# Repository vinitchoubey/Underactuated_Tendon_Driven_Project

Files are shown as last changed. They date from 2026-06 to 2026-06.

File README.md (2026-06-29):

# Underactuated_Tendon-Driven_Robotic_Gripper

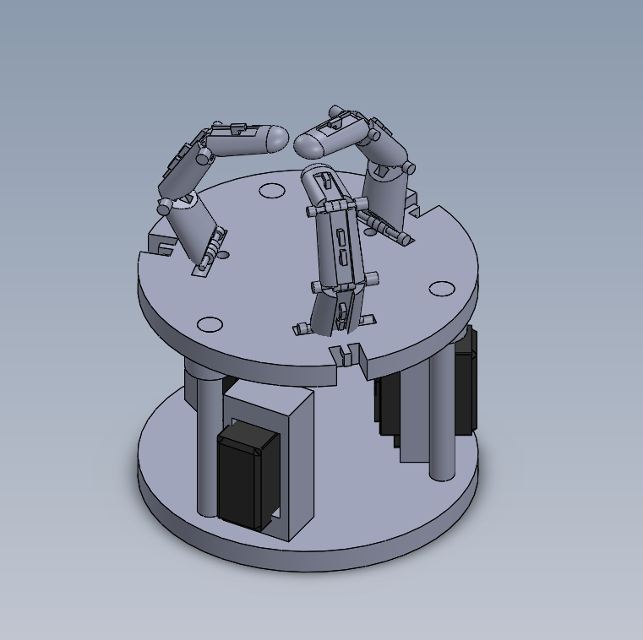
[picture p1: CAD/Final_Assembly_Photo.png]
Gripper


---

## Overview

Design and fabrication of an underactuated, tendon-driven robotic gripper developed
as part of the ME205 Design Lab-1 course at IIT Ropar.

The **Tri-Tendon Gripper** is a 3-finger robotic hand that uses only 3 MG996R servo
motors to control 9 degrees of freedom. Instead of dedicating one motor per joint,
each tendon drives an entire finger — making the system lightweight, energy-efficient,
and capable of adapting to different object shapes automatically.

**Course:** ME205 – Design Lab-1  
**Institution:** IIT Ropar (Indian Institute of Technology, Ropar)  
**CAD Software:** SolidWorks 2021  
**Guide:** Dr. Manish Agrawal

---

## Demo

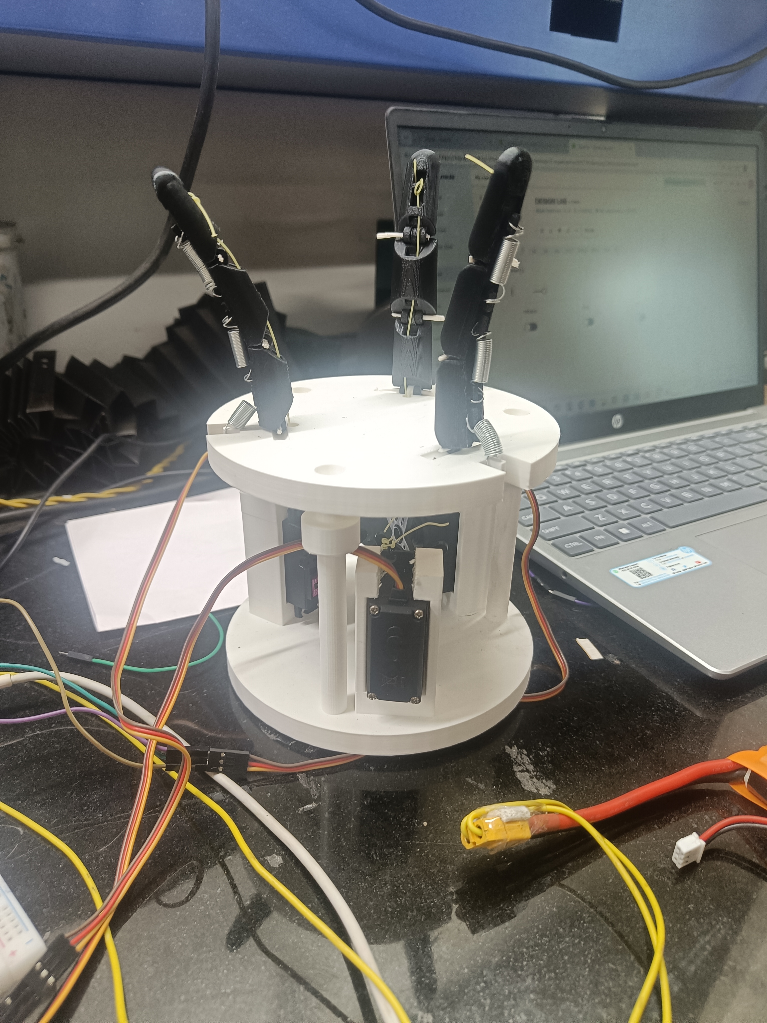
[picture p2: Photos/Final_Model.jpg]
Working Model


[Watch Video Demonstration](Videos/Project_Showcase.mp4)

---

## Working Principle

- **Closing:** Servo motors pull the tendons, curling the fingers inward while
  elongating the return springs mounted at the back of each joint
- **Opening:** When the motor releases, the stretched springs contract and pull
  the fingers back to the open position (passive return)
- **Adaptive Grasping:** Since tendons are not fixed to a single joint, fingers
  automatically wrap around the object's shape without complex programming

---

## Mechanical Design

- 3-finger underactuated structure with 3 joints per finger (9-DOF total)
- Tendons attached to circular servo horns — displacement follows `d = r·sin(θ)`
- Variable spring stiffness across finger length produces a natural curling sequence
- Servos mounted at the base (not on fingers) to minimize moving mass
- Staggered motor start times prevent current spikes and finger collisions

---

## Electronics and IoT

- **Microcontroller:** Arduino Uno R4 WiFi
- **Control Interface:** Blynk IoT platform — mobile app sliders map to servo
  positions via Virtual Pins
- **Power:** DC-DC Buck Converter regulating supply to 6.0V, isolating motor
  current spikes from Arduino logic

---

## Files

| Folder/File | Contents |
|---|---|
| `CAD/` | SolidWorks part and assembly files (.SLDPRT, .SLDASM) |
| `PROJECT_REPORT.pdf` | Full project report |
| `Videos/` | Working model demonstration videos |
| `CAD/Final_Assembly_Photo.png` | CAD render |
| `Photos/` | Physical model photos |

---

## Skills Demonstrated

- CAD modelling and 3D-printed prototype fabrication
- Underactuated mechanism design
- Tendon-spring actuation system
- Arduino programming and IoT integration (Blynk)
- Power electronics and motor control

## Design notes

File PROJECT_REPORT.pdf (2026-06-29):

DESIGN LAB-1
ME-205

### DESIGN AND FABRICATION OF AN UNDERACTUATED TENDON-DRIVEN ROBOTIC GRIPPER

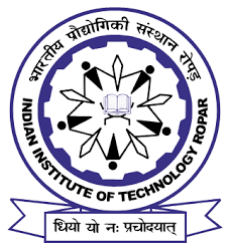
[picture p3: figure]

## DEPARTMENT OF MECHANICALENGINEERING INDIAN INSTITUTE OF TECHNOLOGY ROPAR RUPNAGAR- 140001, INDIA

THU-GROUP(B)

Sr.no | NAME | ENTRY NUMBER
1 | VINIT KUMAR CHOUBEY | 2024MEB1400
2 | UTKARSH SHUKLA | 2024MEB1395
3 | RANVEER GOYAL | 2024MEB1375
4 | SAMEER KUMAR PURBEY | 2024MEB1382
5 | SHIVAM BADYAL | 2024MEB1387

Under the Guidance of: Dr. Manish Agrawal

### TABLE OF CONTENTS

1. Project Overview | Page 3
2. Working Principle | Page 4
3. Mechanical Design and Mechanism | Page 5
- 3.1 Underactuated Finger Motion
- 3.2 Actuation and Transmission (Radial Attachment)
- 3.3 Passive Return Using Springs
- 3.4 Speed and Torque Tuning
4. Under-Actuation and Adaptive Grasping | Page 7
5. Electronics and IoT Integration | Page 8
6. Comparative Analysis | Page 10
7. References and Sources | Page 11

ABSTRACT

This project is about designing and building the Tri-Tendon Gripper, an underactuated, string-driven robotic hand developed at IIT Ropar. Instead of using many motors, we kept the system simple by using just three MG996R servo motor motors to control a total of nine degrees of freedom.

The gripper can automatically adjust its shape while holding objects, so it doesn’t need complicated programming for each joint. It uses a combination of active pulling (through tendons) to close the fingers and a passive spring system to open them again, based on Hooke’s Law.

We controlled the system using an Arduino Uno R4 WiFi along with the Blynk IoT platform, which allowed us to operate the gripper remotely. Overall, this design is lightweight, energy-efficient, and much simpler compared to traditional robotic hands that rely on complex mechanisms and multiple motors.

## 1. Project Overview

Our team designed and prototyped a three-finger robotic gripper based on a string-actuated (tendon-driven) mechanism. The idea was to create a lightweight and efficient system that can perform complex finger movements without relying on many motors.

The final design, which we call the Tri-Tendon Gripper, uses a 9-degree-of-freedom (9-DOF) finger structure but is controlled using only three main tendon lines. Each tendon drives multiple joints in a finger, making the system underactuated.

This approach allows the gripper to automatically adapt to different object shapes while keeping the design simple, compact, and energy-efficient compared to traditional multi-motor systems.

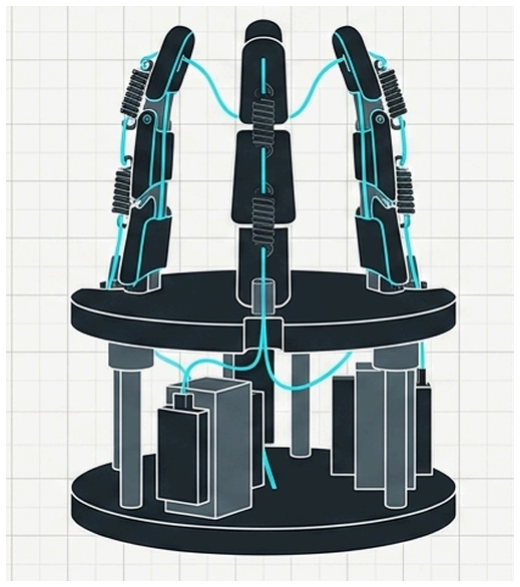
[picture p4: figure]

Fig: String actuated gripper model

## 2. Working Principle

Since our nylon strings can only pull and not push , we had to brainstorm a way to get the fingers to actually open back up once the motor lets go. We went with a "passive" system using springs, which kept the project low-cost and much easier to build.

Instead of using anything complicated, we built normal compression springs directly into the finger joints.

Storing Energy: When our high-torque motors pull the tendons to close the hand, the strings pull against these springs and "squish" them down. This process stores up what is called elastic potential energy inside the spring coils.

The Reset: The moment the motor relaxes the string, all that stored energy is released. The springs push back out to their original shape, which snaps the fingers back into a straight, open position.

The Science: This whole process follows Hooke’s Law. it means that the Force the spring pushes back with is equal to the Stiffness of the spring multiplied by the Distance it was squished. This was a clever trick for our group because it meant we only needed half as many motors, which made our wiring and our Arduino code way easier to manage.

## 3. Mechanical Design and Mechanism

3.1 Underactuated Finger Motion

- Our gripper uses a 3-finger underactuated design, where each finger has multiple joints but is controlled by a single tendon.
- Instead of fixing exact joint angles, the fingers move depending on how they touch the object.
- This helps the fingers naturally wrap around objects, making the grip more adaptive and reliable.

3.2 Actuation and Transmission (Radial Attachment)

- We used MG996R servo motor motors, with tendons attached to holes on a circular servo horn instead of a spool.
- As the servo rotates, the tendon attachment point moves in a circular path, pulling the tendon.
- The tendon movement depends on the servo angle and radius: d=rsin(θ)
- This setup gives higher torque at the start of motion, which helps overcome initial resistance in the system.

3.3 Passive Return Using Springs

- Since tendons can only pull, we added compression springs to bring the fingers back to the open position.
- While closing, the motor expands the springs and stores energy in them.

Ep=0.5*k(Δx)^2

- When the motor releases, the springs come back to original position and help reopen the fingers automatically.

3.4 Speed and Torque Tuning

- Because the springs resist motion during closing, we adjusted the servo speeds differently for each action.
- Grip (85): slower movement to provide more torque and avoid damaging the tendon or stalling the motor.
- Retract (105): faster movement to quickly release the tendon while springs assist in opening.
- This tuning made the system smoother, more stable, and easier to control.

For a continuous servo, 90 is the neutral value → the motor stops.

Values below 90 → rotate in one direction.

Values above 90 → rotate in the opposite direction.

To optimize performance, our team focused on reducing the weight of the moving parts and improving the structural integrity of the hand.

### Design Advantages

- The servos are placed at the base instead of on the fingers, which reduces moving mass and makes the system faster and more efficient.
- Using tendons and springs adds flexibility, so the gripper can handle small impacts without damaging the motor gears.
- This flexible setup acts like a natural shock absorber, making the system safer and more durable.

- It also helps the fingers adjust easily to different object shapes, improving grip without needing complex control

## 4. Under-Actuation and Adaptive Grasping

The defining feature of this project is under-actuation—using only three motors to control nine individual joints.

The Curling Sequence: We achieved a natural "hooking" motion by varying the spring stiffness across the finger. By placing stiffer springs at the base and more flexible springs at the tips, the finger naturally curls from the tip inward, ensuring a more secure wrap around the object.

Adaptive Grasping Capability

- Our tendons are not tied to just one joint, so the fingers can adjust themselves automatically.
- If one part of a finger touches the object early, the tendon keeps pulling the other joints.
- This makes the finger wrap naturally around the object’s shape instead of stopping midway.
- Because of this, the gripper can handle different shapes and sizes easily without extra control.

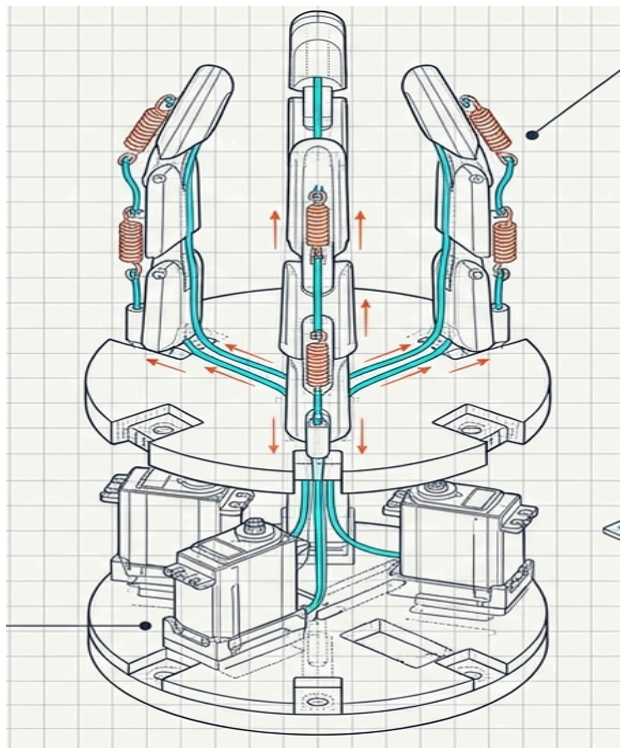
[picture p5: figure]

Fig: anatomy of a gripper system

## 5. Electronics and IoT Integration

The system is powered by the Arduino Uno R4 WiFi, which handles the logic for both local and remote control.

- IoT Interface: We used the Blynk IoT platform for real-time mobile control. We assigned Virtual Pins to represent the finger positions. When a slider is moved on the phone app, the Arduino receives the data and converts it into movement signals for the servos.
- Power Management: A major challenge was the "current spikes" from the motors, which can reset the Arduino. We solved this by adding an external

Buck Converter. This device acts as a steady regulator, keeping the motor power at a constant 6.0 Volts while isolating it from the Arduino's sensitive logic circuits.
- Collision Prevention: To prevent the fingers from crashing into each other, we wrote a "staggered" control script. Instead of moving all fingers at once, the code introduces a tiny delay between each one: Start Time of Finger 2 = Start Time of Finger 1 + Time Delay This also prevents the power system from being overloaded by all three motors starting at the exact same millisecond.

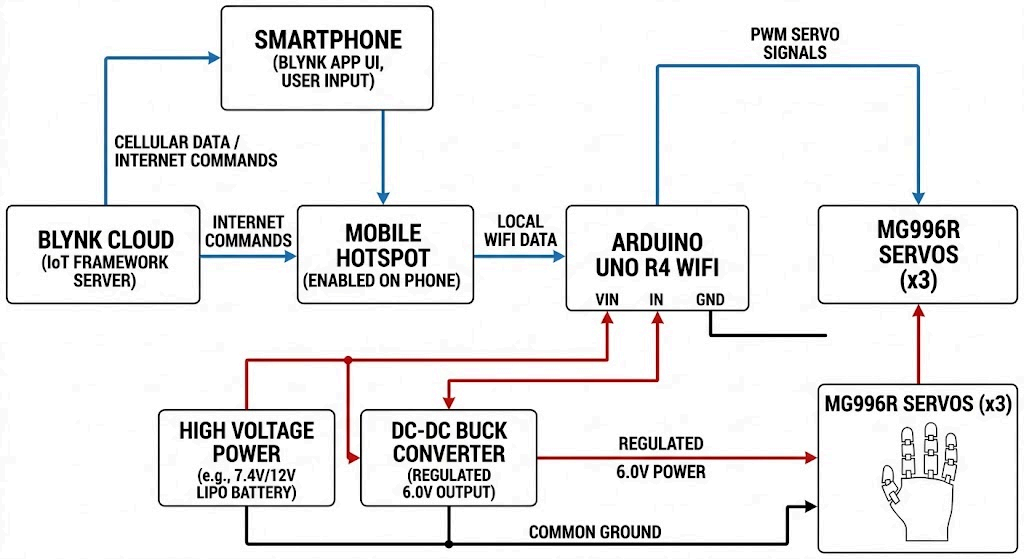
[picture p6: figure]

Fig: system architecture

## 6. Comparative Analysis

The following table summarizes why the Tri-Tendon design was chosen over traditional linkage-based systems.

Feature | Our Tri-Tendon Gripper | Regular Robotic Grippers
Weight | Very light fingers (motors stay in the palm). | Heavy fingers (motors are on the joints).
Shape | Wraps around any shape | Only moves in one fixed way.
Motor Count | Only 3 motors for 9 joints. | Usually needs 9+ motors to do the same thing.

## 7. References and sources

- Birglen, L., & Gosselin, C. M. (2004). "Kinetostatic Analysis of Underactuated Robotic Hands."
- Dollar, A. M., & Howe, R. D. (2010). "The SDM Hand: A Highly Adaptive and Robust Grasping Manipulator."
- Blynk IoT Documentation. "Virtual Pins and Hardware Interfacing for Arduino Uno R4 WiFi." (2024).
- Modular Open-Source Hand Research - Guided our 3D-printing and low-cost design choices.

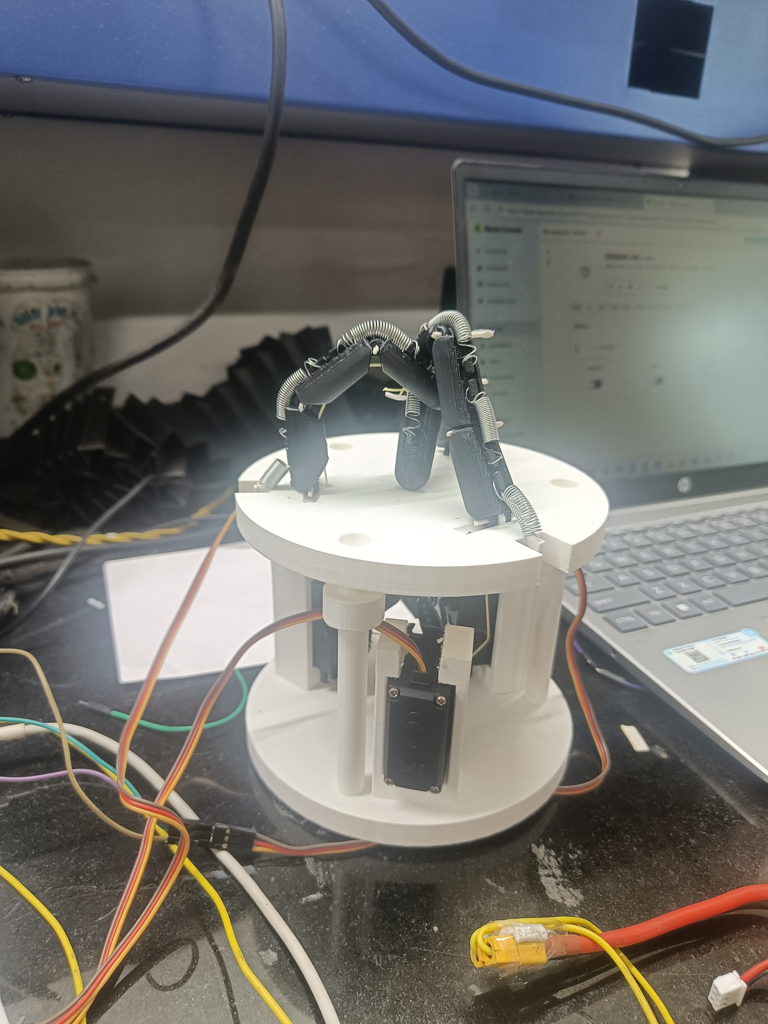
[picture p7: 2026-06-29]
Photos/Closed_Position.jpg

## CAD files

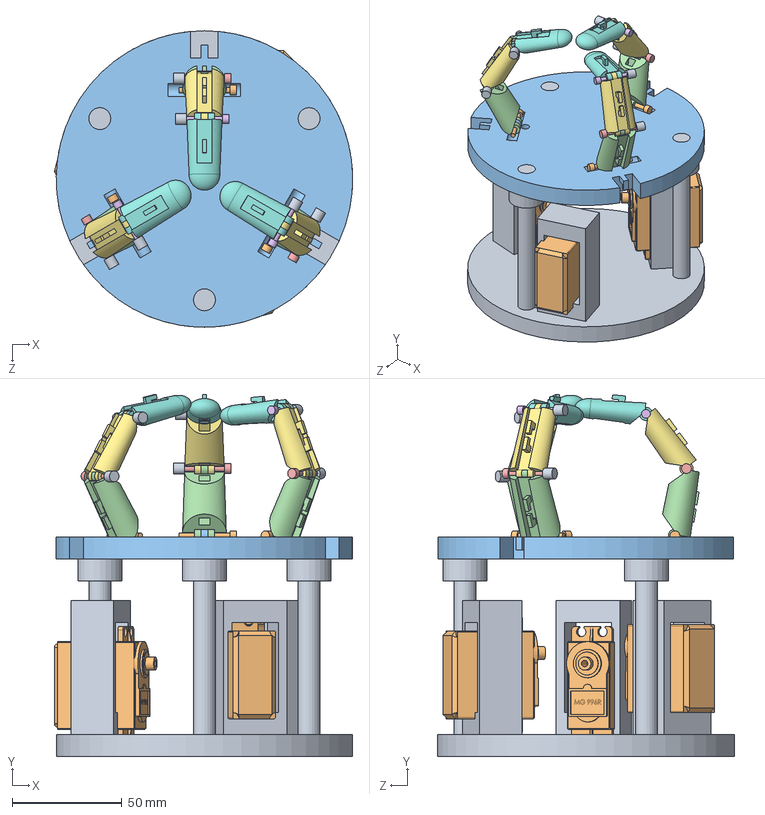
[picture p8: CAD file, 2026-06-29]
CAD/Final Assembly.SLDASM
135.9 x 164.8 x 135.0 mm
Lower Base
##Servo_MG_996R x 3
Upper Base
Base Bone x 3
Finger Joint 1 x 3
Finger Joint 2 x 3
Middle Bone x 3
Tip Bone x 3
Finger Joint 1 cap x 6
Finger Joint 3 x 3

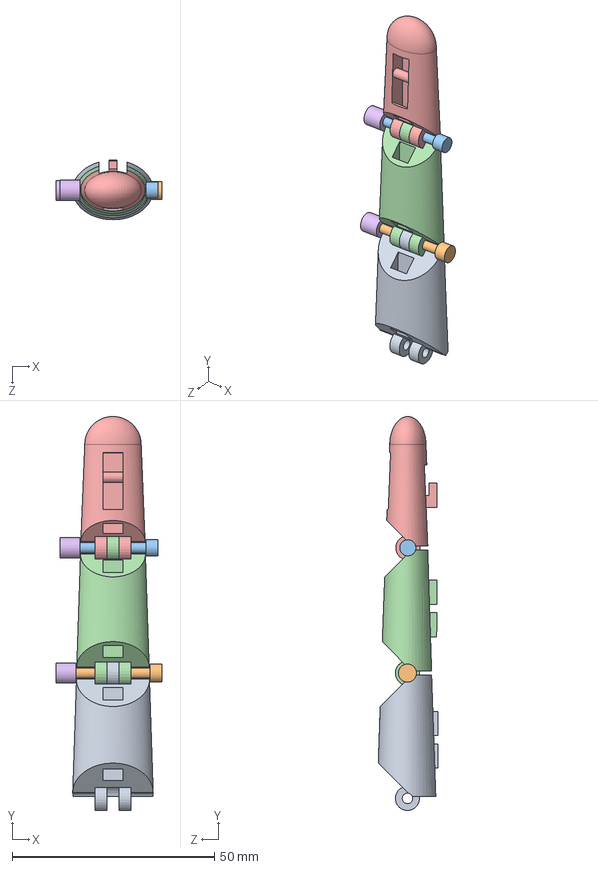
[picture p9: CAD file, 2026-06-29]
CAD/Finger Assembly.SLDASM
26.3 x 97.5 x 14.7 mm
Base Bone
Finger Joint 1
Finger Joint 2
Middle Bone
Tip Bone
Finger Joint 1 cap x 2

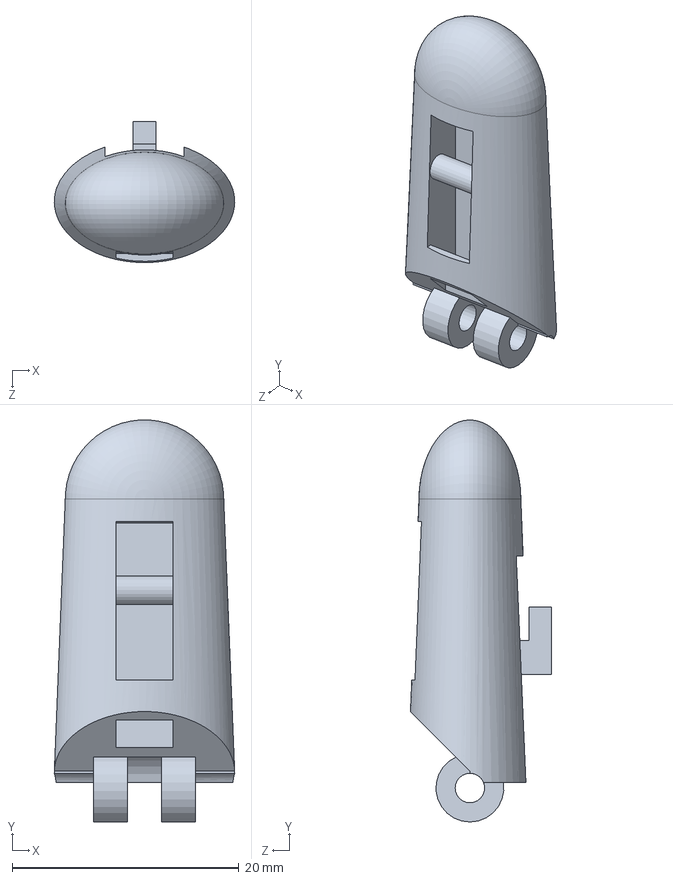
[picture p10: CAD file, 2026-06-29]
CAD/Tip Bone.SLDPRT
15.9 x 35.5 x 12.5 mm

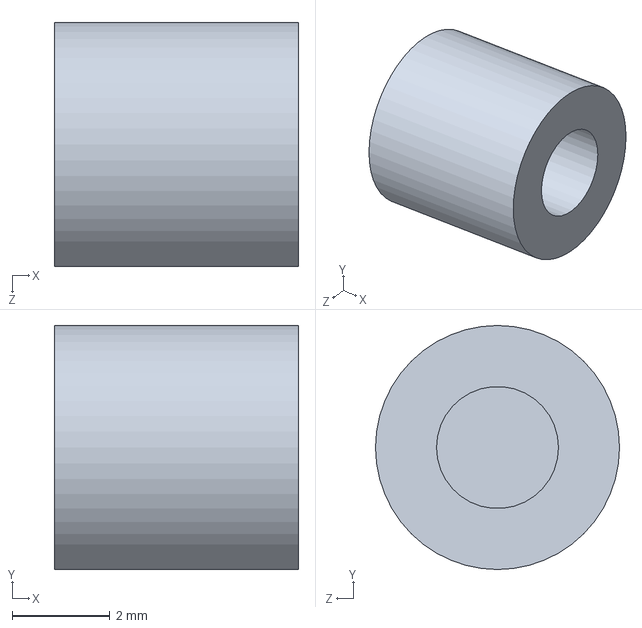
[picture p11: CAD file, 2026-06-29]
CAD/Finger Joint 1 cap.SLDPRT
5.00 x 5.00 x 5.00 mm

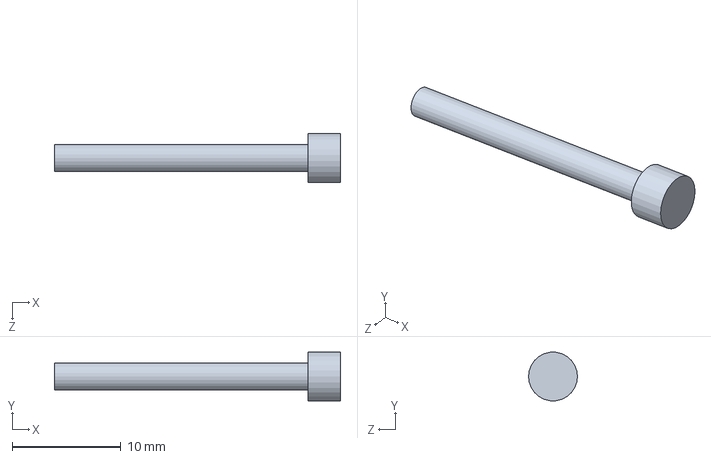
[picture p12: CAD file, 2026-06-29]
CAD/Finger Joint 3.SLDPRT
26.3 x 4.47 x 4.50 mm

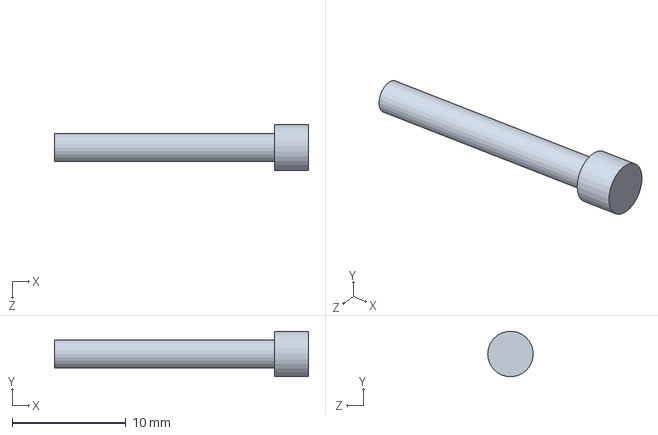
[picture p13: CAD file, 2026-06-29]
CAD/Finger Joint 2.SLDPRT
22.3 x 3.99 x 4.00 mm

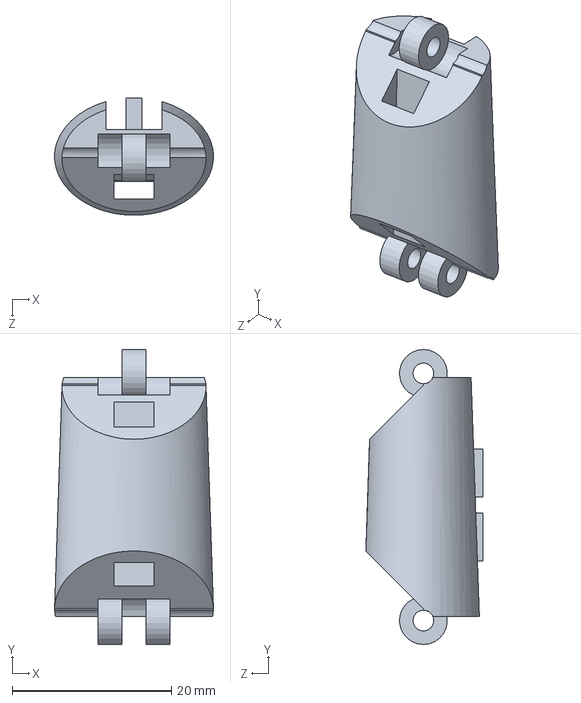
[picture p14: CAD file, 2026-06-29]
CAD/Base Bone.SLDPRT
19.9 x 37.0 x 14.7 mm

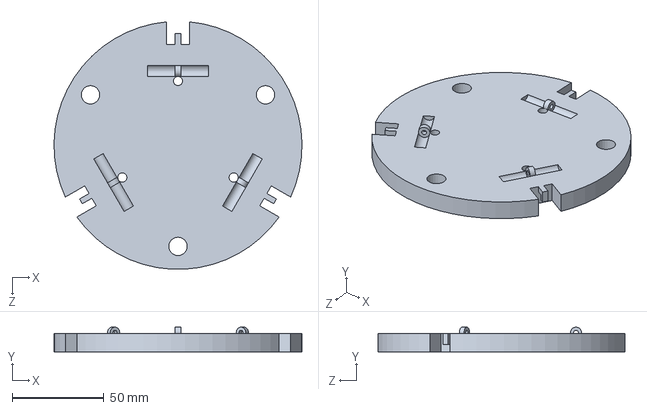
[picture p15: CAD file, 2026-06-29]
CAD/Upper Base.SLDPRT
135.0 x 13.5 x 134.6 mm

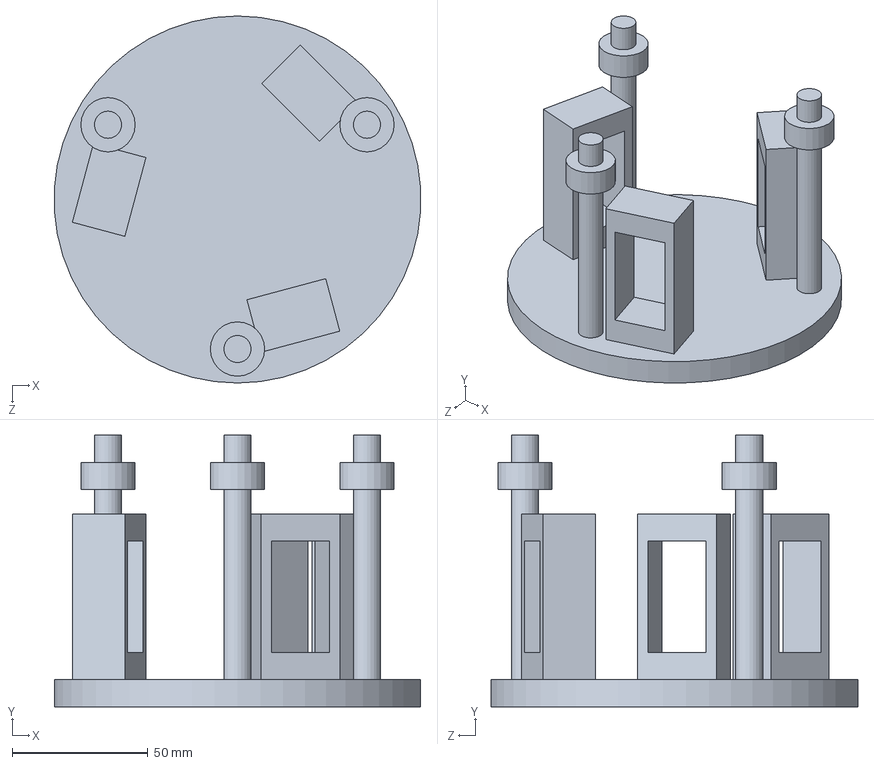
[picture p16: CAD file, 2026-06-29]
CAD/Lower Base.SLDPRT
134.7 x 100.0 x 135.0 mm

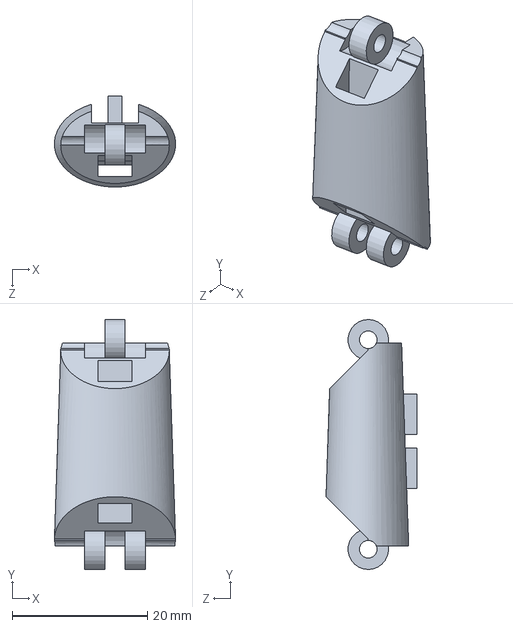
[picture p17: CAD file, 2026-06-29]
CAD/Middle Bone.SLDPRT
17.9 x 37.0 x 13.5 mm

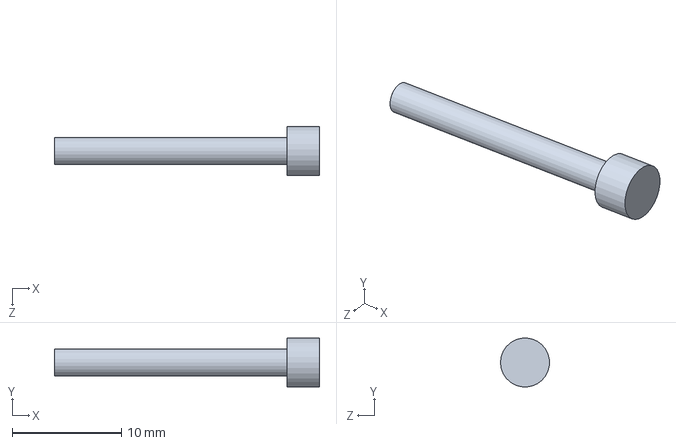
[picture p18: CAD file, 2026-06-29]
CAD/Finger Joint 1.SLDPRT
24.3 x 4.49 x 4.50 mm

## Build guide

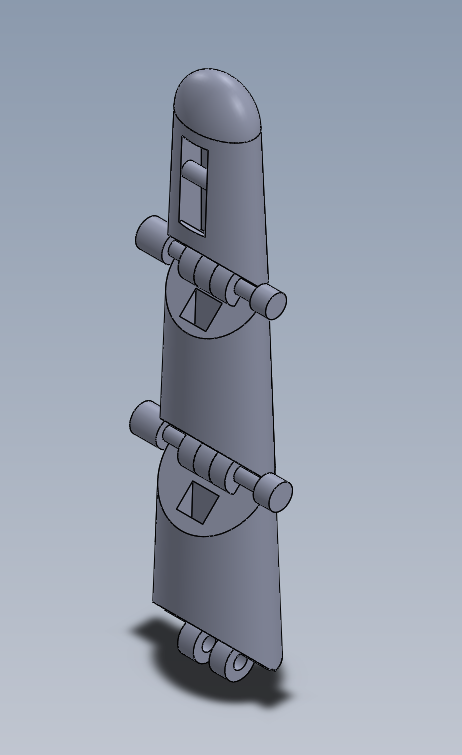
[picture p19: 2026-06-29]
CAD/Finger Assembly 1.png

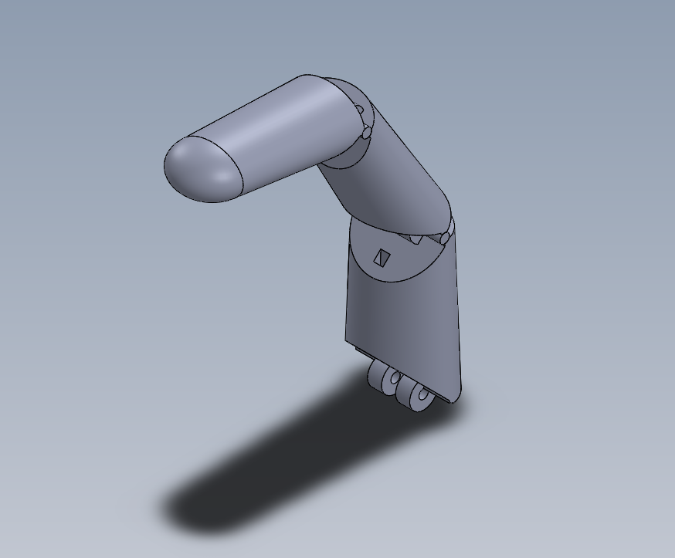
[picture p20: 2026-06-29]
CAD/Finger Assembly 2.png

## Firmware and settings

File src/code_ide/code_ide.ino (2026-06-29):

#define BLYNK_TEMPLATE_ID "TMPL3ZWLu1XRT"
#define BLYNK_TEMPLATE_NAME "DESIGN LAB"
#define BLYNK_AUTH_TOKEN "7_gWYwq_PiAepl6b-ZvccmFhrDrXQ_j9"

#include <WiFi.h>
#include <WiFiClient.h>
#include <BlynkSimpleEsp32.h>
#include <ESP32Servo.h>

Servo f1, f2, f3;

char auth[] = BLYNK_AUTH_TOKEN;
char ssid[] = "Realme P3 Pro"; 
char pass[] = "111111101";     

int pin1 = 18;
int pin2 = 19;
int pin3 = 21;
int stopPoint = 90; 

int speedGrip = 85;   
int speedRetract = 105; 

void setup() {
  Serial.begin(115200);
  
  ESP32PWM::allocateTimer(0);
  ESP32PWM::allocateTimer(1);
  ESP32PWM::allocateTimer(2);
  ESP32PWM::allocateTimer(3);
  
  f1.setPeriodHertz(50);
  f2.setPeriodHertz(50);
  f3.setPeriodHertz(50);

 
  Blynk.begin(auth, ssid, pass);

  f1.attach(pin1); 
  f2.attach(pin2); 
  f3.attach(pin3);

  f1.write(stopPoint); 
  f2.write(stopPoint); 
  f3.write(stopPoint);
  
  Serial.println("ESP32 System Ready (Pins 18, 19, 21)!");
}

BLYNK_WRITE(V0) {
  if (param.asInt() == 1) {
    Serial.println("Grip: ON");
    f1.write(speedGrip); f2.write(speedGrip); f3.write(speedGrip);
  } else {
    Serial.println("Grip: STOP");
    f1.write(stopPoint); f2.write(stopPoint); f3.write(stopPoint);
  }
}


BLYNK_WRITE(V2) {
  if (param.asInt() == 1) {
    Serial.println("!!! MANUAL STOP !!!");
    f1.write(stopPoint); f2.write(stopPoint); f3.write(stopPoint);
  }
}


BLYNK_WRITE(V3) {
  if (param.asInt() == 1) {
    Serial.println("Retract: ON");
    f1.write(speedRetract); f2.write(speedRetract); f3.write(speedRetract);
  } else {
    Serial.println("Retract: STOP");
    f1.write(stopPoint); f2.write(stopPoint); f3.write(stopPoint);
  }
}

void loop() {
  Blynk.run();
}

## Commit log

2026-06-29 commit for the tendon-driven gripper project
    [Base Bone.SLDPRT, Final Assembly.SLDASM, Finger Assembly.SLDASM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]
2026-06-29 Update gripper control code in code_ide.ino
2026-06-29 Add missing src folder and project files
    [code_ide.ino]
